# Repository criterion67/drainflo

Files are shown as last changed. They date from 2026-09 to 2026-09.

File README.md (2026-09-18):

# DrainFlo

A local, cloud free automatic vinegar doser for an HVAC condensate drain line.

Once a month it pumps one cup of distilled white vinegar into the drain line cleanout, then tells you it worked. No subscription, no cloud account, no app. Everything runs in Home Assistant on your own network.

It replaces the monthly chore of climbing into the attic with a measuring cup.

**Reference build cost: about $77 in parts plus roughly 60 g of filament.** The relay was bought on sale, and the hookup wire, connectors and leak sensor were already on hand. Per-part prices are in the [bill of materials](docs/02-bill-of-materials.md).

---

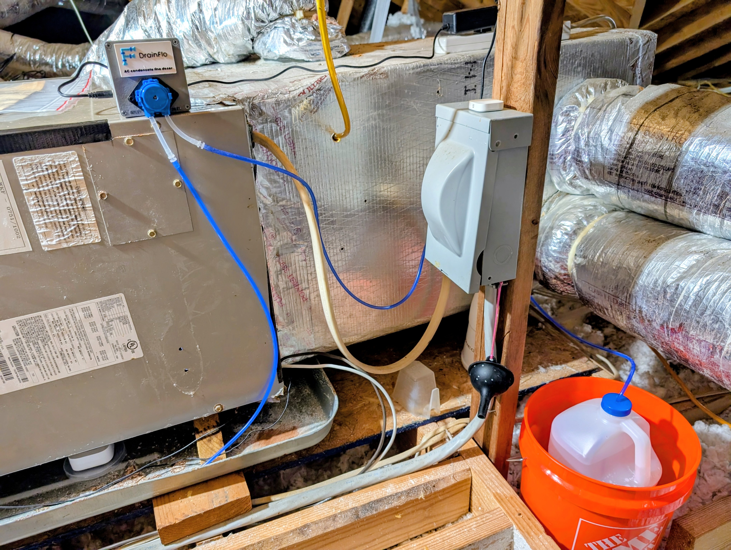
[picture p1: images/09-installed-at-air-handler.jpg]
The finished DrainFlo install at the attic air handler

*The finished install. Enclosure on the air handler, vinegar jug in its containment bucket, tubing run to the drain line cleanout.*

---
## Why I built this

Commercial automatic drain line dosers exist. The one that prompted this project is cloud dependent and uses proprietary cartridges of its own cleaning fluid, which means an account you have to keep, a service that has to stay running, and a consumable you can only buy from one place at a price they set.

None of that is necessary to squirt a cup of vinegar down a pipe once a month.

DrainFlo runs entirely on your own network. There is no account, no app, no telemetry and nothing to subscribe to. The consumable is a gallon of distilled white vinegar from the grocery store, and a gallon lasts about 16 months. If the company that made your relay disappears tomorrow, the system keeps working, because nothing in it phones home.

That principle is worth more than the money. A cloud product is only as permanent as its vendor's business model, and hardware bolted to your house should outlive that.

---

## What it does

- Doses one cup of vinegar at 05:00 on the 15th of every month
- Confirms the pump actually ran, and tells you when it did not
- Tracks how much vinegar is left in the jug and warns you before it runs out
- Force stops the pump if it ever runs longer than it should
- Runs entirely locally over Zigbee or WiFi

## What it is not

This is not a certified product. It is a pump moving liquid above your ceiling, and the thing preventing an overflow is software you are choosing to trust. **Read [docs/08-safety.md](docs/08-safety.md) before you build it.** Containment and a leak sensor are requirements, not suggestions.

---

## Documentation

| Document | Contents |
|---|---|
| [01 Overview](docs/01-overview.md) | How the system works and why it is designed this way |
| [02 Bill of materials](docs/02-bill-of-materials.md) | Every part, with sizes and substitution notes |
| [03 Enclosure](docs/03-enclosure.md) | Printing and assembling the box, lid and badge |
| [04 Plumbing](docs/04-plumbing.md) | The cleanout cap, tubing, jug and containment |
| [05 Wiring](docs/05-wiring.md) | Six connections, with the terminal map |
| [06 Home Assistant](docs/06-home-assistant.md) | Installing the package, pairing the relay |
| [07 Calibration](docs/07-calibration.md) | Measuring your pump's actual flow rate |
| [08 Safety](docs/08-safety.md) | Failure modes and what protects against each |
| [09 Troubleshooting](docs/09-troubleshooting.md) | Known issues, including the Zigbee timer problem |
| [10 ESPHome](docs/10-esphome.md) | Alternative controller with a hardware enforced runtime limit |
| [11 Shelly setup](docs/11-shelly-setup.md) | Device side setup and the three settings that protect you |

## Repository layout

```
cad/              STEP and STL files for the enclosure, lid and badge
docs/             Build documentation
esphome/          Alternative ESP32 controller: shareable project + personal config
homeassistant/    Drop in package: helpers, scripts, automations
images/           Photos, diagrams and the logo
```

---

## Printed parts

| Part | Download | Print time |
|---|---|---|
| Enclosure box | [STEP](cad/Vinegar_Doser_Box_80x80x53.step) / [STL](cad/Vinegar_Doser_Box_80x80x53.stl) | ~2 h |
| Lid with pump mount | [STEP](cad/Vinegar_Doser_Lid_pump_mount.step) / [STL](cad/Vinegar_Doser_Lid_pump_mount.stl) | ~40 min |
| DrainFlo badge, optional | [STEP](cad/DrainFlo_Badge_drop_A_full_tagline.step) | ~25 min |

About 60 g of filament all in. Print settings and orientation in [03 Enclosure](docs/03-enclosure.md).

---
## A finding worth knowing before you start

**The Shelly 1 Gen4 exposes no auto off timer when running in Zigbee mode.** The Zigbee `on_time` attribute is silently ignored: send it and the relay turns on and stays on. This is not documented by Shelly and it is the single most important thing to understand about this build, because it means the off command depends entirely on Home Assistant being alive.

DrainFlo compensates with three independent software cutoffs plus physical containment. Full detail in [docs/08-safety.md](docs/08-safety.md) and [docs/09-troubleshooting.md](docs/09-troubleshooting.md).

If you want a device side watchdog, either run the relay on WiFi instead of Zigbee, where the Shelly web interface exposes a real auto off, or use the [ESPHome controller](docs/10-esphome.md), which enforces its own maximum runtime on the microcontroller with no network involved.

---

## License

MIT. See [LICENSE](LICENSE).

## Disclaimer

DrainFlo is an independent, non commercial, open source project. It is not affiliated with, endorsed by, sponsored by, or connected to any commercial product, company or brand. Any similarity between this project's name and any trademark is unintentional and no association is implied.

Nothing is sold here and no money changes hands. The repository contains documentation and design files, published freely for anyone who wants to build their own.

## Use of AI

Portions of this project were developed utilizing AI assistance. The concept, design, physical build and all testing are mine, and all measurements in these docs came off my own bench.

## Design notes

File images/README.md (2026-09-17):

# Images

Build photos from the reference installation, in build order.

| File | What it shows |
|---|---|
| `00-parts-laid-out.jpg` | Core parts before assembly: 12V supply, Shelly 1 Gen4, barrel jacks, tubing |
| `00b-bench-setup.jpg` | Wider view of the same parts on the bench |
| `01-pump-mounted-on-lid.jpg` | Pump flange bolted to the lid with the motor hanging through the bore, box open beside it |
| `02-enclosure-wiring.jpg` | Motor leads and relay wiring joined with lever nuts, lid off |
| `03-relay-and-junctions.jpg` | Top down into the box: relay in its pocket, the two junction points, barrel jack in the wall |
| `04-enclosure-finished.jpg` | Closed enclosure with the DrainFlo badge, pump head and tubing on the outside |
| `05-cleanout-injection-point.jpg` | Tubing entering the drilled PVC cleanout cap, with the condensate safety switch on the tee |
| `06-jug-cap-tubing-and-vent.jpg` | Jug cap close up: pickup tubing pressed through, and the vent hole beside it |
| `07-jug-in-containment-bucket.jpg` | Vinegar jug standing in the containment bucket, tubing routed up to the cleanout |
| `08-leak-sensor-in-bucket.jpg` | Leak sensor in the bottom of the bucket beside the jug |
| `09-installed-at-air-handler.jpg` | The finished install at the attic air handler |

## Still to add

| Subject | Why it would help |
|---|---|
| A dose complete notification on the phone | Shows what the system actually tells you |
| Printed badge close up | The four color emboss detail |

## Diagrams

| Subject | Status |
|---|---|
| Wiring diagram, the six connection terminal map | Not yet added; see [docs/05-wiring.md](../docs/05-wiring.md) |
| DrainFlo logo | Not yet added |

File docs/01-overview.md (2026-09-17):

# 01 Overview

## The problem

An air handler pulls moisture out of the air and drains it away through a PVC condensate line. That line is dark, permanently damp and full of organic debris, which is ideal for algae and biofilm. Left alone it clogs.

When the primary line clogs, water backs up into the drain pan and out the secondary line, which usually discharges somewhere deliberately annoying so you notice. If the secondary is also blocked, or there is no float switch, the pan overflows into the ceiling.

The standard prevention is a cup of distilled white vinegar down the cleanout once a month. It works. The problem is remembering to do it, and in many houses the cleanout is in an attic.

## The approach

A small peristaltic pump, a jug of vinegar and a relay that Home Assistant can switch. Once a month the automation closes the relay for a measured number of seconds, the pump delivers one cup, and the relay opens again.

Three properties drove the design:

**Local only.** No cloud account, no vendor API, nothing that stops working when a company changes its business model. The relay speaks Zigbee or WiFi to your own network.

**No fittings in the liquid path.** The pump's own silicone tubing runs unbroken from the jug to the drain line, pressed through a hole drilled in a spare cleanout cap. Every fitting is a potential leak, so there are none.

**Containment by default.** The jug sits inside a bucket sized to hold more than the jug contains. This is not optional.

## How a dose works

```
05:00 on the 15th
        |
        v
Is the relay reachable?  ---- no ---->  raise fault, notify, stop
        |
       yes
        v
Close the relay
        |
        v
Wait 5 seconds, did it actually report on?  ---- no ---->  force off, raise fault, notify
        |
       yes
        v
Wait the remaining dose time
        |
        v
Open the relay
        |
        v
Decrement dose counter, update next due date, notify success
```

The verification step matters. A relay that has silently dropped off the network will accept a turn on command that goes nowhere, and without checking you would believe the drain line was dosed when it was not.

## Components of the system

**Pump.** A 12V DC peristaltic dosing pump. Peristaltic because the rollers occlude the tube when idle, which means the pump itself blocks backflow and no check valve is needed. Also self priming and tolerant of running dry.

**Relay.** A dry contact relay that can be powered from the same 12V supply. Dry contact rather than a mains switch means one power supply for the whole build.

**Controller.** Home Assistant. It holds the schedule, runs the dose, verifies it, counts remaining vinegar and raises the alarms.

**Enclosure.** A printed box that holds the relay and carries the pump on its lid, so the pump motor hangs inside and the wet end stays outside.

**Containment.** A bucket under the jug, with a leak sensor in the bottom of it.

## Design decisions worth explaining

**Dose by time, not by volume.** There is no flow meter. The pump runs at a known rate, so the dose is a calibrated number of seconds. This drifts as the pump tube takes a set, which is why [07 Calibration](07-calibration.md) tells you to re measure occasionally.

**05:00 on a fixed day.** Early morning puts the attic near its daily minimum temperature, which matters because these pumps are typically rated only to 40C and an attic exceeds that by afternoon. A fixed day of the month rather than a rolling 30 day countdown keeps the schedule predictable and lets you avoid whatever day your other notifications land on.

**The counter is open loop.** Home Assistant cannot see inside the jug. The dose counter is a budget that decrements on each dose and resets when you tell it you refilled. If you refill and never acknowledge it, the count drifts low. The consequence is a false low vinegar warning, not a failure, but it is worth knowing.

**The fault flag does not self clear.** If a dose is missed, the warning stays up until you dismiss it. A relay coming back online does not mean the drain line got its vinegar.

## Next

Start with [02 Bill of materials](02-bill-of-materials.md).

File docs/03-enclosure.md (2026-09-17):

# 03 Enclosure

Three printed parts. The box holds the relay, the lid carries the pump, and the badge is decorative.

## Files

| Part | Download | What it is |
|---|---|---|
| Box | [STEP](../cad/Vinegar_Doser_Box_80x80x53.step) / [STL](../cad/Vinegar_Doser_Box_80x80x53.stl) | 80 x 80 x 53 mm box with relay pocket and barrel jack hole |
| Lid | [STEP](../cad/Vinegar_Doser_Lid_pump_mount.step) / [STL](../cad/Vinegar_Doser_Lid_pump_mount.stl) | Lid with 31 mm pump bore, reinforcing boss and M3 slots |
| Badge | [STEP](../cad/DrainFlo_Badge_drop_A_full_tagline.step) | Optional four color badge, 60 x 34 x 2.1 mm. STEP only, see the Badge section |

STEP files are provided so you can modify dimensions. STL files are provided for printing directly.

## Print settings

Developed on a Bambu Lab P2S with a 0.4 mm nozzle.

| Setting | Value | Why |
|---|---|---|
| Layer height | 0.20 mm | |
| Wall loops | 4 | The lid boss carries a cantilevered motor |
| Infill | 30% | |
| Supports | None | Both parts are self supporting in the orientations below |
| Material | PLA or PETG | PETG if your attic runs above roughly 55C |

**Orientation matters.** The box prints opening upward, floor on the plate. The lid prints flat face down with the reinforcing boss pointing up. Printing the lid the other way up needs supports under the entire boss overhang.

## Box features

- **Relay pocket**, 42.05 mm between the internal rails. A Shelly 1 Gen4 is 42.0 mm wide, so this is a press fit with essentially no clearance. If yours will not seat, file the inner faces of the two rails. They only locate the relay and carry no load.
- **11 mm hole** in one wall for the panel mount barrel jack, with an 18 mm reinforcing boss on the inside so the jack's nut has a flat seat and something to torque against.
- **Four corner posts** with 2.8 mm pilot holes, 7 mm deep from the rim.

## Lid features

- **31 mm bore** offset from center, positioned so the motor hangs beside the relay rather than above it. The relay's height therefore does not constrain the design.
- **6 mm reinforcing boss** on the inner face, bringing material under the pump flange to 8 mm total.
- **Two M3 slots** elongated along the bore's long axis, covering flange screw pitches from about 46 to 49 mm.

## Assembly

1. **Test fit the relay** in the box pocket before anything else. File the rails if tight.
2. **Fit the barrel jack** through the 11 mm hole. Gasket outside, nut inside against the boss. Hand tight plus a little.
3. **Mount the pump to the lid.** Flange on the outside of the lid, motor hanging through the bore. M3 x 16 screws down through the flange, washers and nuts on the inside of the boss. **Do this with the lid off the box**, flat on a bench. Reaching inside a 53 mm box with two wrenches is miserable.
4. **Wire it** per [05 Wiring](05-wiring.md), still with the lid off.
5. **Close the lid** with four M3 x 10 screws into the corner posts. Do not exceed 10 mm: past that the screw leaves the pilot hole and enters the hollow post, where it grips nothing and can split it.

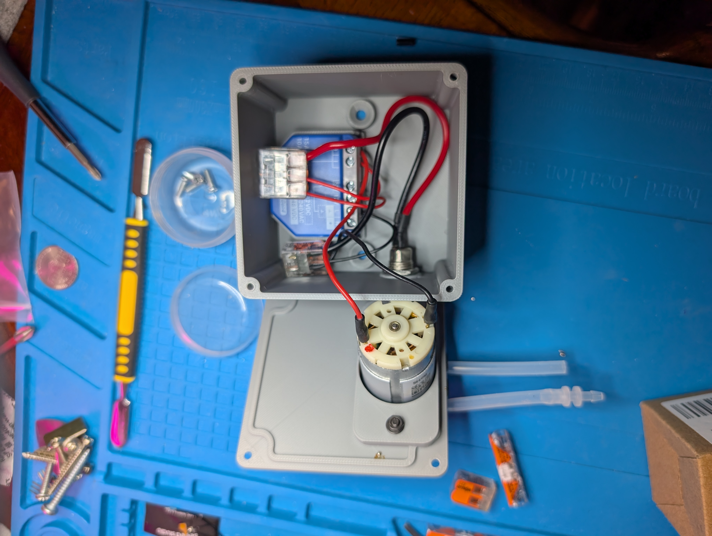
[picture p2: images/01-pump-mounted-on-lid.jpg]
Pump bolted to the lid with the motor hanging through the bore

*Pump mounted to the lid before the lid goes on the box. Flange outside, motor hanging through the bore. Do this on a bench, not reaching into a 53 mm box.*

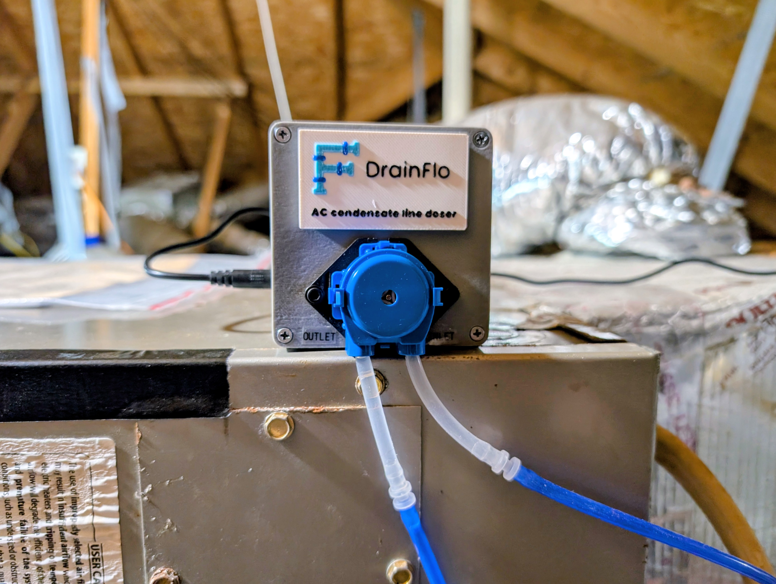
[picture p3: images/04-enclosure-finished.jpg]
The closed enclosure with the DrainFlo badge

*The finished enclosure. Badge above the pump bore, INLET and OUTLET labelled on the lid.*
## Badge

Optional. Four colors in a single 0.6 mm raised layer band, so a multi material system purges once rather than per feature.

The STEP file imports as one object with four named bodies. Assign a filament to each: base black, pipe light blue, joints dark blue, text white.

Print four at once. Purge waste is charged per color change per layer, not per object, so spares are nearly free.

Attach with VHB or double sided foam tape to the lid's outer face, above the pump bore. Clearances are tight, roughly 2 mm to the bore and 2.6 mm to the nearest corner screw recess, so do not scale it up.

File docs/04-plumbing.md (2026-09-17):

# 04 Plumbing

There are no fittings in the liquid path. The pump's own silicone tubing runs unbroken from the jug to the drain line. Every joint you do not have is a joint that cannot leak.

## The cleanout cap

Most condensate drain lines have a vertical riser with a cap on top, which is where you would normally pour vinegar. Many are friction fit rather than glued.

**Buy a spare cap and drill that one.** They cost a couple of dollars and it keeps your original as a fallback.

1. Identify your cap size. 3/4 inch Schedule 40 is common; the part number is usually moulded into it.
2. Drill a **3/16 inch hole** in the top of the spare cap. That is 4.76 mm against 5 mm tubing, which gives a press fit that grips.
3. Push the tubing through. Warm or wet the end and twist it. If you drill 5 mm it will slide out over time.
4. Cut the tubing so it hangs about **3 inches into the riser**, ending in open air.
5. Fit a zip tie on the tubing just above the cap as a mechanical stop, so it cannot creep down over the years.

**The tube end must never sit in standing water.** If it does, you give condensate a path to wick back up.

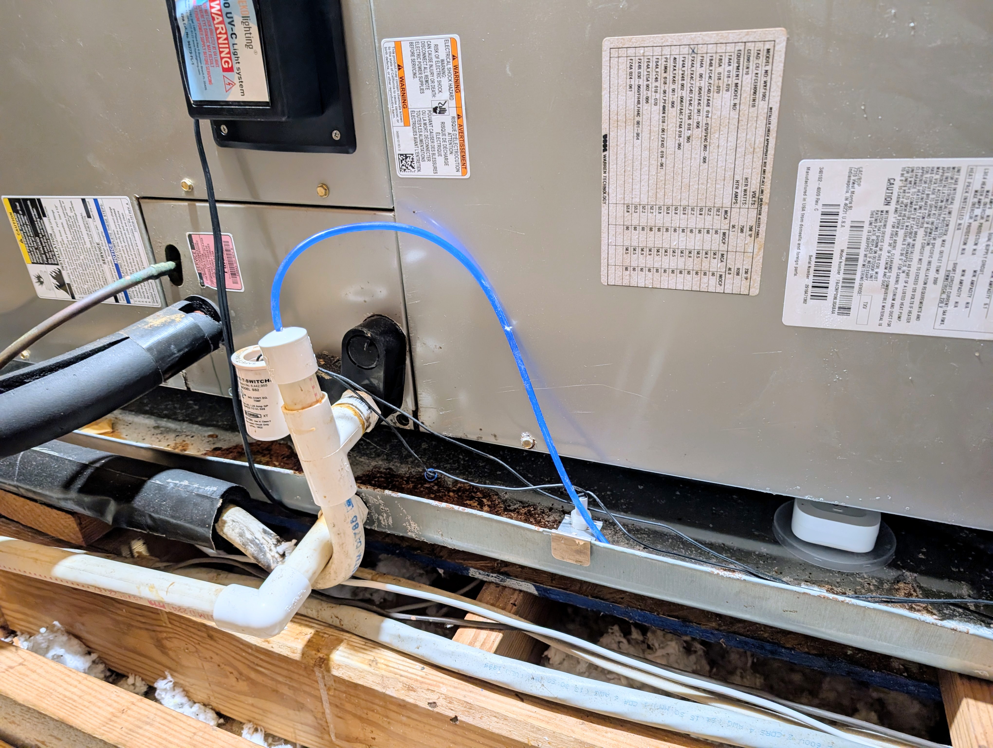
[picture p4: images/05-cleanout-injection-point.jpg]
Tubing entering the drilled PVC cleanout cap

*The injection point. Tubing pressed through a 3/16 inch hole drilled in a spare cleanout cap, hanging about 3 inches into the riser. No fittings anywhere in the liquid path.*
## Why not a fitting

Earlier iterations of this build used a threaded stack: a glued female adapter, a reducing bushing and a barbed fitting. It works but adds three leak paths, several inches of height, and a corrosion question. Vinegar attacks brass, and stainless grade matters above 50C.

A hole and a press fit has none of those problems and costs nothing.

## The jug

Use the jug the vinegar came in. HDPE, rigid, already the right shape. Drill two holes in its cap.

**Pickup hole:** 3/16 inch, press fit for the tubing. Cut the tube so it ends about 5 mm off the bottom of the jug. Close enough to draw nearly all of it, far enough that it cannot seal against the floor.

**Vent hole:** about 3 mm. This one must stay in the **air space above the liquid**, never below it.

The vent exists because as the pump draws liquid out, air has to get back in or the jug collapses and the pump starves. Attic heat expanding the air above the vinegar is the second reason.

**A vent tube must not reach into the liquid.** If it does, you have built a siphon and the jug will empty itself.

If you fit a short stub of tube in the vent hole, run it outside the jug, loop it downward, and end it inside the containment bucket. Attic heat can push vapour or a little liquid out, and the loop catches it.

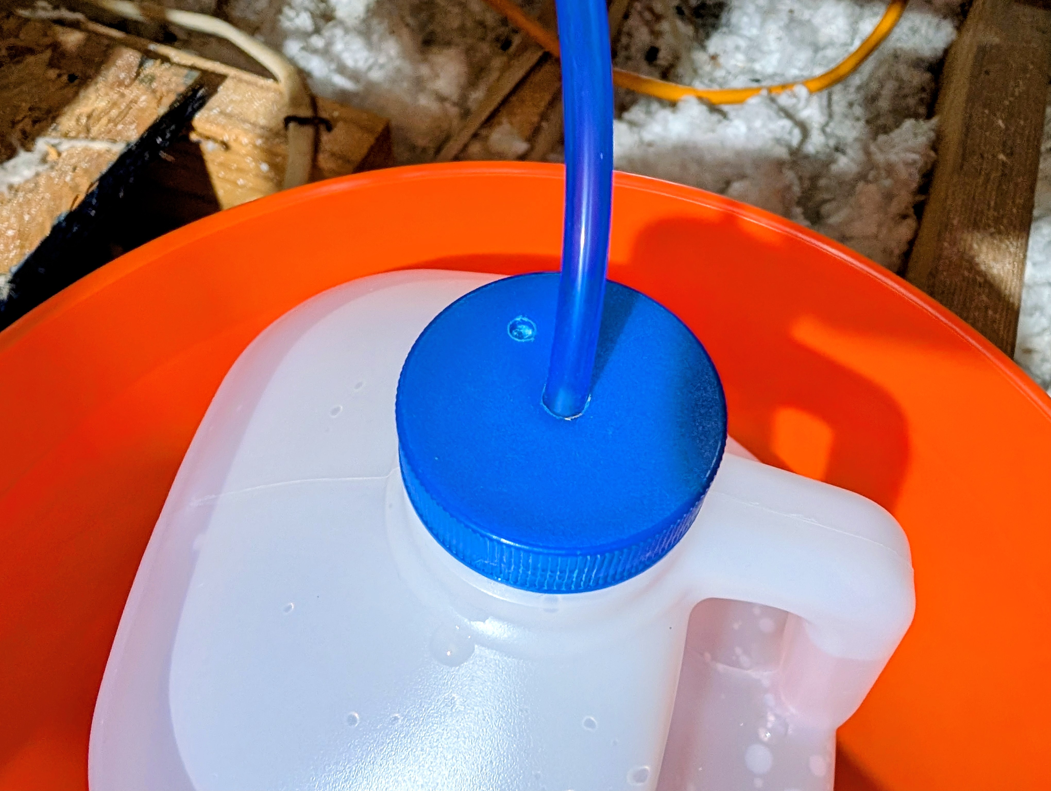
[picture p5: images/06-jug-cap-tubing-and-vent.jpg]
Jug cap with the pickup tubing pressed through and the vent hole beside it

*The jug cap. Pickup tubing press fit through a 3/16 inch hole, and the 1/8 inch vent hole beside it, staying in the air space above the liquid.*
## Containment

**This is a requirement, not a suggestion.**

The jug sits inside a bucket whose capacity exceeds the jug's. A 1 gallon jug in a 2 gallon bucket gives you a full jug failure fully contained.

Put a **water leak sensor in the bottom of the bucket**, beside the jug. Containment without detection means you find out at the next refill.

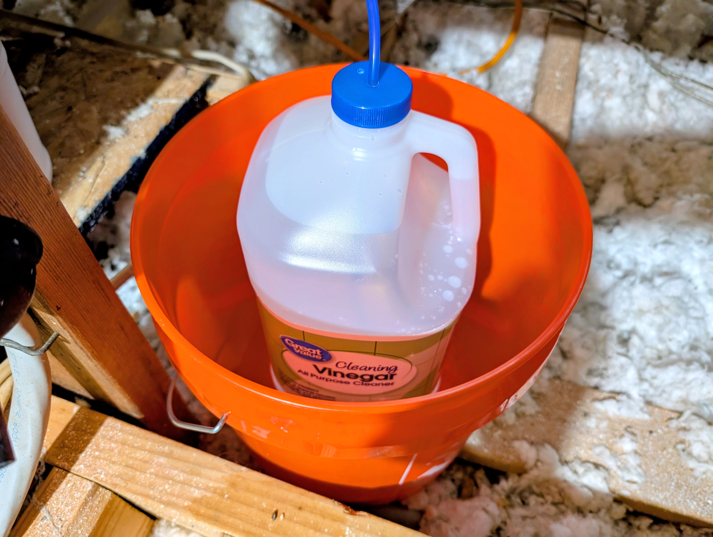
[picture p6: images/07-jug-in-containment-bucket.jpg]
Vinegar jug standing in the orange containment bucket

*A 1 gallon jug inside a 2 gallon bucket. A full jug failure is fully contained.*

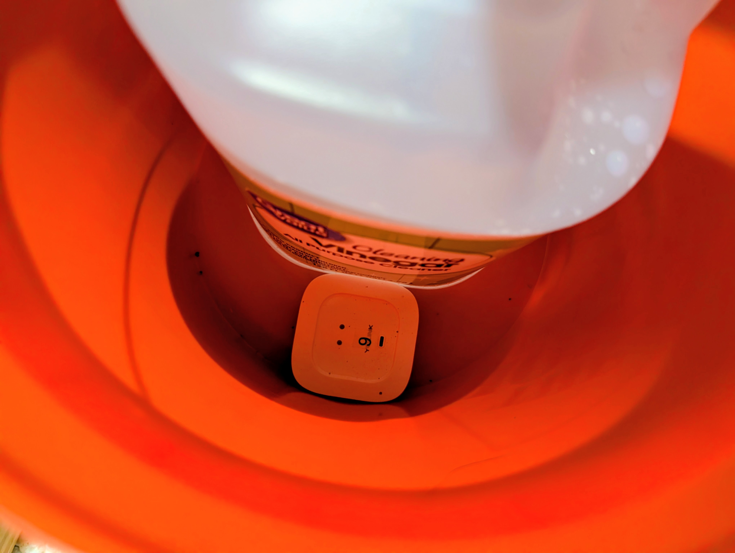
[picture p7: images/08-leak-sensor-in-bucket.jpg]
Leak sensor in the bottom of the bucket beside the jug

*The leak sensor goes in the bottom of the bucket, beside the jug. Containment without detection just delays the discovery.*
## Layout

Two rules:

**The jug sits lower than the injection point.** The pump self primes easily over that height, and it means no head pressure is trying to push liquid toward the drain line if anything fails.

**Nothing pulls on the jug.** Route the tubing so no tug can tip it inside the bucket.

## Which tube is which

Run the pump and feel both ends. One will be under suction, and that is the inlet: it goes into the jug. The other goes to the cap.

A peristaltic pump is a brushed DC motor, so reversing the leads reverses the flow direction. If your inlet and outlet are the wrong way round, swap the two pump wires.

Mark both tubes as soon as you know.

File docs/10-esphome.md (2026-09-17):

# 10 ESPHome controller

An alternative to the commercial relay. Costs less, requires soldering, and gives you something the Zigbee relay cannot: **a maximum runtime enforced on the microcontroller itself**, with no network involved.

If Home Assistant dies mid dose, the ESP32 still shuts the pump off.

## Which to choose

| | Commercial relay | ESPHome |
|---|---|---|
| Controller cost | ~$28 | ~$8 |
| Soldering | None | Yes |
| Hardware watchdog on Zigbee | **No** | **Yes** |
| Hardware watchdog on WiFi | Yes | Yes |
| Setup | Pair and go | Flash and go |

## Parts

| Part | Spec | Approx. |
|---|---|---|
| Seeed XIAO ESP32C3 | With the external antenna it ships with | $5 |
| IRLB8721PBF | Logic level N channel MOSFET, TO-220 | $1 |
| Resistors | One 100 ohm, one 10k | pennies |
| MP1584EN module | Adjustable buck converter | $2 |

**Use the C3, not the S3.** The C3 has no PCB antenna at all and relies entirely on the external one it ships with, which is what you want through attic framing. The S3 buys nothing here and runs warmer.

**Use the IRLB8721, not the IRLZ44N** that most tutorials name. The IRLZ44N specifies its on resistance at 5 V gate drive and is marginal on a 3.3 V GPIO pin. The IRLB8721 has guaranteed on resistance at lower gate voltages and much lower gate charge.

**No flyback diode needed.** At roughly 12 switching cycles a year against a 0.4 A motor, it earns nothing.

## Circuit

One 12 V supply enters through the panel barrel jack and feeds two things: the pump, and an MP1584EN buck converter that makes 5 V for the XIAO.

```
12V+ ──┬── Pump +
       └── MP1584EN IN+ ── (set to 5.0V) ── XIAO 5V pin

Pump − ── MOSFET drain
MOSFET source ── 12V−
MOSFET gate ── 100 ohm ── XIAO GPIO5
MOSFET gate ── 10k ── 12V−

12V− ── XIAO GND, MP1584EN IN−, MOSFET source   (all common)
```

**Set the buck to 5.0 V with a meter before connecting the XIAO.** These modules ship at an arbitrary voltage set by a multi turn trimpot. Feeding the 5 V pin anything above about 5.5 V destroys the board.

**The 10k pulldown is not optional.** Without it the gate floats during boot and the pump can twitch.

**All grounds must be common.** The gate voltage is measured against source, so an ungrounded reference means unpredictable switching.

### Two supplies instead

You can skip the buck and power the XIAO from a separate USB-C supply. It works, and removes the trimpot step. **You must still tie the two grounds together**, or the gate has no reference to the pump's return path.

The reason the buck is preferred: the enclosure has one hole for one power connector, and nowhere for a second cord.

## Pin choice

GPIO5, which is silkscreened D3. Confirm against the pinout for your board.

**Avoid GPIO2, GPIO8 and GPIO9.** They are strapping pins on the ESP32C3 and pulling them at boot changes how the chip starts.

## Two configurations

**[`esphome/drainflo.yaml`](../esphome/drainflo.yaml)** is the shareable project file. It contains no credentials, sets up Improv provisioning over both USB serial and Bluetooth, and carries the `dashboard_import` block that lets anyone adopt the device into their own ESPHome Device Builder. Flash this one.

**[`esphome/drainflo-personal.yaml`](../esphome/drainflo-personal.yaml)** is a conventional config using `!secret` for WiFi, API and OTA credentials. Use this if you would rather manage the device the normal way.

## Flashing

Flash the first time over USB at a bench, not in the attic. After that everything is OTA.

Provisioning is via Improv: either plug it into a computer and use the ESPHome web installer, or use Bluetooth from the Home Assistant app. No credentials are baked into the firmware.

## What it exposes

| Entity | Purpose |
|---|---|
| Dispense Dose | Runs one full dose |
| Prime Pump | 20 seconds, for filling the line |
| Stop Pump | Aborts everything and forces off |
| Dose Duration | Your calibrated seconds per cup |
| Pump Running | Binary sensor |
| Restart ESP | |

**The raw pump switch is deliberately not exposed.** It is marked internal, so everything goes through the dose script and the pump cannot be left running by a stray toggle in the Home Assistant UI.

## Two layers of runtime protection

**The script** turns the pump off after `dose_seconds`.

**The switch itself** kills it at `max_run_seconds`, 300 by default, through an `on_turn_on` automation with `mode: restart`. This runs on the ESP with no network involved, so a dead WiFi link or a crashed Home Assistant still ends with the pump off.

That second layer is the entire reason to choose this over the Zigbee relay. See [08 Safety](08-safety.md).

## Using it with the Home Assistant package

The package in `homeassistant/packages/drainflo.yaml` switches `switch.drainflo`. The ESPHome device does not expose a switch, it exposes a button.

Change the dose branch to press `button.drainflo_dispense_dose` instead of toggling a switch, and drop the delay and the turn off, since the device handles its own timing. The safety cutoff and startup force off branches become redundant but are harmless to leave in place.

**Containment is still required.** A hardware watchdog reduces the risk, it does not remove it.

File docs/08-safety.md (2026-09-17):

# 08 Safety

Read this before building. It is the most important document in the repository.

## What you are building

A pump that moves liquid, mounted above a ceiling, with software deciding when it stops.

That is the whole risk in one sentence. Everything below follows from it.

## The primary failure mode

**The relay closes and does not open.**

If that happens and nothing intervenes, the pump keeps running until the jug is empty. A gallon of vinegar goes into your drain line far faster than it can drain, backs up, and overflows the pan into the ceiling.

## What the Shelly does not do

**In Zigbee mode the Shelly 1 Gen4 provides no device side auto off.**

The Zigbee `on_time` attribute is silently ignored. Publishing `{"state": "ON", "on_time": 300}` turns the relay on and it stays on indefinitely, with no error and no indication that the timer was dropped. A plain `{"state": "ON"}` to the same topic works, which confirms the topic is correct and the attribute specifically is being discarded.

This is not documented by Shelly. It was found by testing, and it is the reason this document exists.

**The consequence: the off command depends entirely on Home Assistant.** If Home Assistant is down, restarting, or has lost the network when a dose is in progress, nothing in the relay will stop the pump.

## What protects you

Four layers, in order from first to last.

**1. The dose sequence turns the pump off.** Normal operation. Turn on, wait, turn off.

**2. A safety cutoff automation.** Triggers when the switch has been on for 6 minutes against a 110 second dose, forces it off, and pushes an urgent notification. This catches a dose sequence that died part way through.

**3. A startup force off.** On every Home Assistant start, the switch is commanded off. This catches the case where Home Assistant crashed mid dose and came back with the relay still closed.

**4. Physical containment.** The jug sits in a bucket larger than the jug. Even if every software layer fails, the vinegar that is not already in the drain line ends up in the bucket.

**The gap that remains:** Home Assistant down for an extended period with the relay closed. Layers 1 to 3 are all software. Layer 4 is what stands between that scenario and your ceiling.

## Requirements, not suggestions

- **A containment vessel that holds more than the jug does.** A 1 gallon jug goes in a 2 gallon bucket.
- **A leak sensor in the bottom of that vessel.** Containment without detection just delays the discovery.
- **Do not skip the safety cutoff automation.** It is in the package for a reason.

## If you want a real hardware watchdog

Two options:

**Run the relay on WiFi instead of Zigbee.** The Shelly's web interface exposes a genuine auto off setting that the device enforces itself. Set it to 300 seconds. Verify it actually works by watching a test dose before you trust it.

**Use the ESPHome controller instead.** [esphome/drainflo.yaml](../esphome/drainflo.yaml) enforces a hard maximum runtime on the microcontroller itself. A dead network or a crashed Home Assistant does not affect it.

## Chemical notes

**Use vinegar, not bleach.** Either ordinary distilled white vinegar at 5 percent acetic acid or cleaning vinegar at 6 percent works. The reference build runs on cleaning vinegar. The stronger acid is no problem for the liquid path, since silicone tubing is rated excellent for 10 percent acetic acid in water, and a higher concentration is if anything more effective against biofilm. What has not been verified here is whether 6 percent behaves differently from 5 against a drain pan or evaporator coil in a backup situation, so if that matters to you, use the 5 percent.

**Never use bleach in a condensate drain line.** It corrodes the evaporator coil and the drain pan.

**If you reuse a bleach jug, rinse it thoroughly and let it dry open first.** Residual hypochlorite meeting acetic acid releases chlorine gas, and an attic is a poor place for that.

**Silicone tubing is fine with dilute acetic acid.** It is rated excellent for 10 percent acetic acid in water. Metal fittings are where the compatibility questions start, which is another reason this build has none.

## Temperature

Most small peristaltic pumps are rated for 0 to 40C ambient. An attic exceeds that on a summer afternoon in most of the United States.

Dosing in the early morning puts the run near the attic's daily minimum, which is why the schedule is at 05:00. Idle storage at high temperature is much less stressful than running at it, but it is a real constraint and worth knowing if you are considering a different schedule.

## Electrical

Everything in this build is 12V DC. There is no mains wiring anywhere.

If you substitute a mains switched relay, that is a different project with different requirements, and this document does not cover it.

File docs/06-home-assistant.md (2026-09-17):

# 06 Home Assistant

## Pairing the relay

### Zigbee (Zigbee2MQTT)

The Shelly 1 Gen4 ships in Matter profile and must be switched to Zigbee first.

**Update the firmware before switching.** Zigbee OTA is not supported, so once it is on Zigbee you cannot update it without switching back.

Two ways to switch:

- **Web interface.** Settings has a Matter to Zigbee toggle, then a Zigbee menu with Start pairing. Status reads Steering while discoverable and Joined on success.
- **Button.** Five quick presses switches profile and opens a 3 minute inclusion window. Three presses reopens it. The presses have to be genuinely fast.

**Switching wipes every setting except the WiFi configuration.** Configure anything device side after the switch, not before.

Name the device `DrainFlo` in Zigbee2MQTT, which yields `switch.drainflo`. Resist adding a room or descriptor, since Z2M builds the entity_id from the friendly name.

### WiFi

Power the relay, join the access point it broadcasts, and browse to `http://192.168.33.1`. Point it at your network, then give it a DHCP reservation.

**On WiFi you get a real auto off timer** in the Shelly web interface. Set it to 300 seconds. This is a genuine device side watchdog and it is the main reason to prefer WiFi for this build. Full device side procedure in [11 Shelly setup](11-shelly-setup.md); see also [08 Safety](08-safety.md).

## Installing the package

Enable packages in `configuration.yaml` if you have not already:

```yaml
homeassistant:
  packages: !include_dir_named packages
```

Copy [`homeassistant/packages/drainflo.yaml`](../homeassistant/packages/drainflo.yaml) into `config/packages/` and restart Home Assistant.

### Three things to change first

| Placeholder | Occurrences | Change to |
|---|---|---|
| `notify.mobile_app_pixel_9` | 9 | Your own notify target |
| `switch.drainflo` | 11 | Your relay's entity_id |
| `delay: seconds: 105` | 1 | Your calibrated dose time minus 5 |

The `Quiet Notices` channel is Android specific. On first use Android creates it silent at low importance. **iOS users should remove the `channel` and `importance` keys** from the notification data blocks.

### Seed the helper values

After the restart:

- `input_number.drainflo_doses_remaining` to **16** for a full gallon
- `input_datetime.drainflo_next_dose` to **the 15th of next month**

## What gets created

**Helpers**

| Entity | Purpose |
|---|---|
| `input_number.drainflo_doses_remaining` | Open loop dose budget, 16 per gallon |
| `input_boolean.drainflo_pump_fault` | Drives the fault card, does not self clear |
| `input_boolean.drainflo_refill_active` | Drives the refill card |
| `input_datetime.drainflo_refill_snooze_until` | 7 day snooze deadline |
| `input_datetime.drainflo_next_dose` | Display only readout |

**Scripts**

| Entity | Purpose |
|---|---|
| `script.drainflo_dose_complete` | Updates the next dose readout, logs |
| `script.drainflo_refilled` | Resets the budget to 16 |
| `script.drainflo_refill_snooze` | Pushes the snooze out 7 days |
| `script.drainflo_clear_fault` | Dismisses the fault state |

**Automations**

| Entity | Purpose |
|---|---|
| `automation.drainflo_dosing` | Dose, verify, safety cutoff, startup force off, offline warning |
| `automation.drainflo_refill_reminder` | Daily low vinegar level check |

## Testing before you trust it

**Run `automation.drainflo_dosing` manually.** Triggering by hand skips the day of month condition, so it doses regardless of the date. Do this with the outlet tube in a container, not in the drain line.

Watch for: the relay closing, the pump running for your dose time, the relay opening on its own, a success notification, and the counter dropping by one.

Afterwards, reset the counter and the next dose date if you want a clean slate.

**Test the safety cutoff too.** Turn `switch.drainflo` on manually and leave it. After 6 minutes it should force off and push on the urgent channel. This is the layer that matters most, so confirm it works rather than assuming.

## Dashboard cards

Two conditional cards, one per boolean, in whatever notification area your dashboard uses:

```yaml
type: conditional
conditions:
  - condition: state
    entity: input_boolean.drainflo_pump_fault
    state: "on"
card:
  type: markdown
  content: >-
    ### DrainFlo pump fault

    The monthly dose did not complete. Dose manually if the line needs it,
    then dismiss.
  card_mod: {}
```

```yaml
type: conditional
conditions:
  - condition: state
    entity: input_boolean.drainflo_refill_active
    state: "on"
card:
  type: markdown
  content: >-
    ### DrainFlo vinegar low

    {{ states('input_number.drainflo_doses_remaining') | int }} doses left.
```

Add tap actions calling `script.drainflo_clear_fault` and `script.drainflo_refilled` respectively. Put a confirmation on both if the dashboard lives on a wall tablet where a stray tap is plausible.

## A note on the reference instance

The reference build reuses a helper named `input_datetime.hvac_drain_line_due_date` and a script named `script.hvac_drain_line_cleaned`, inherited from the manual reminder system DrainFlo replaced. The package uses clean `drainflo_` names throughout. Functionally identical.

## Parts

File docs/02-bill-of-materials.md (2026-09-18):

# 02 Bill of materials

Prices are approximate as of late 2026 and exclude shipping.

**No affiliate links anywhere in this repository.** Every link is a plain product link with tracking parameters stripped. If you fork this and add referral links, please say so in your README.

Links are provided for convenience and go stale quickly. **The spec column is what actually matters.** Match the specification, not the listing.

## Core parts

| Part | Spec | Approx. | Link | Notes |
|---|---|---|---|---|
| Peristaltic dosing pump | Kamoer NKP, 12V DC, 3mm ID x 5mm OD | $10 | [link](https://www.amazon.com/dp/B07GWJ78FN) | See selection notes below |
| Dry contact relay | Shelly 1 Gen4, UL listed | $28 | [link](https://www.amazon.com/dp/B0H8YW595V) | Often on sale; the reference build paid $18. Must accept 12V DC power. See alternatives below |
| Silicone tubing | 3mm ID x 5mm OD, 9.8 ft | $9 | [link](https://www.amazon.com/dp/B0FMF45JZH) | Must match the pump's tube size |
| Panel mount barrel jack | 5.5 x 2.1 mm, 11 mm panel hole | $6 for 6 | [link](https://www.amazon.com/dp/B0GGN5MWH5) | Only one needed |
| 12V DC power supply | 12V 2A, center positive, 5.5 x 2.1 mm plug | $7 | [link](https://www.amazon.com/dp/B0BZP8CYD1) | The plug must be 2.1 mm to match the jack; a 2.5 mm plug sits loose. 1A is enough. Meter the polarity before use |
| Vinegar | 1 gallon, cleaning or distilled white | $4 | [link](https://www.walmart.com/ip/GV-Vinegar-128oz/15941853266) | Its own HDPE jug is the reservoir |
| Containment bucket | 2 gallon | $5 | [link](https://www.homedepot.com/p/The-Home-Depot-2-gal-Homer-Bucket-RG502HD/316355946) | Must exceed the jug's capacity |
| Water leak sensor | Any Home Assistant compatible | $15 to $30 | see below | Goes in the bottom of the bucket. Options in the next section |
| Wire connectors | Two 3 way joints, one 2 way | under $1 | hardware store | Plain wire nuts are fine. Lever nuts are nicer to work with: [WAGO 221-413](https://www.amazon.com/dp/B0GLHLRZR4) $7 for 10 and [221-412](https://www.amazon.com/dp/B072PT3JNL) $6 for 10 |
| Hookup wire | 18 AWG, a few feet | on hand | [link](https://www.amazon.com/dp/B0DXKKCS5R) | Any 18 AWG will do. The reference build used 18/3 thermostat cable left over from another job |
| Spare PVC cleanout cap | Matching your existing cap | $2, optional | hardware store | Recommended. The reference build drilled the cap already on the riser, which works but leaves no undrilled cap to seal the line with later |
| M3 x 16 machine screws, nuts, washers | 2 of each | $2 for both sizes | hardware store | Pump flange to lid |
| M3 x 10 machine screws | 4 | included above | hardware store | Lid to box |

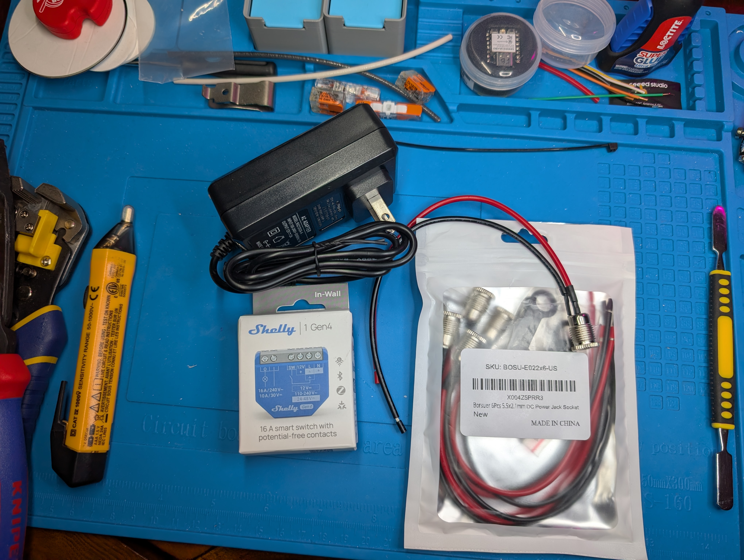
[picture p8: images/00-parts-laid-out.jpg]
Core parts laid out on the bench before assembly

*Most of the core parts: 12V supply, Shelly 1 Gen4, panel mount barrel jacks, silicone tubing, lever nuts.*
## Leak sensor options

**This is the part people skip, and it is the one that tells you the containment bucket did its job.** Without it you find out at the next refill.

Any sensor Home Assistant can see will do. A few that work:

| Sensor | Protocol | Approx. | Link |
|---|---|---|---|
| YoLink YS7903 | YoLink, needs a YoLink hub | $25 | [link](https://www.amazon.com/dp/B07Z7QWJBP) |
| ThirdReality WL2 | Zigbee, needs a Zigbee coordinator | $15 | [link](https://www.amazon.com/dp/B0GK19F6Z2) |
| Aqara T1 | Zigbee, needs a Zigbee coordinator | $18 | [link](https://www.amazon.com/dp/B0DWXHMFQS) |
| Shelly Flood S Gen4 | WiFi, Bluetooth, Zigbee or Matter | $30 | [link](https://www.amazon.com/dp/B0H3QG45XL) |

The reference build uses the YoLink because one was already on hand.

**If you have no hub of any kind, the Shelly Flood S Gen4 is the one to get.** Per its listing it speaks WiFi as well as Zigbee and Matter, so it can reach Home Assistant on your network alone. The other three need a coordinator or bridge you may not own, which turns a $15 sensor into a $60 purchase.

**Put it in the bottom of the bucket, beside the jug.** Not on the platform next to the air handler. A pan sensor tells you the drain line clogged, which is a different failure. This one tells you the vinegar jug leaked.
## Pump selection

The build was developed around a **Kamoer NKP 12V** with a 3mm ID x 5mm OD tube. Any similar 12V DC peristaltic dosing pump will work. What to match:

- **12V DC brushed motor.** Avoid stepper driven pumps, which need a driver board.
- **Tube size 3mm ID x 5mm OD.** If yours differs, the cap hole and tubing in the docs change accordingly.
- **Flow rate roughly 70 to 150 mL/min.** Faster pumps dose too coarsely for a one cup target. The measured unit in this build delivered about 135 mL/min.
- **Snap in pump head if available.** Tube replacement without tools is worth a lot when the pump lives in an attic.

The enclosure CAD assumes a **29 mm diameter, 48.5 mm long motor with a 54.5 x 40.3 mm flange and screws 47 to 48.5 mm apart.** The lid's mounting holes are slots, so the pitch tolerance is covered, but a very different motor needs the bore resized.

## Relay selection

The relay must satisfy three things:

1. **Dry contact output** so the pump is switched independently of the relay's own power
2. **12V DC input**, so one supply runs everything
3. **Local control** from Home Assistant

The Shelly 1 Gen4 meets all three. Note the important caveat about its Zigbee mode in [09 Troubleshooting](09-troubleshooting.md).

**Do not use the Shelly 1 Mini Gen4.** It has dry contacts but is AC powered only, with no DC input.

Other dry contact relay modules that take 12V DC work equally well. Generic Zigbee dry contact modules are around $17.

## Alternative: ESP32 controller

Instead of a commercial relay you can drive the pump from a microcontroller. This costs less and gives you a hardware enforced maximum runtime, at the price of soldering.

| Part | Approx. |
|---|---|
| Seeed XIAO ESP32C3 | $5 |
| IRLB8721PBF MOSFET | $1 |
| 100 ohm and 10k resistors | pennies |
| MP1584EN buck converter module | $2 |

Not yet built, so no links. These are stock parts available from any electronics supplier.

Full detail in [10 ESPHome](10-esphome.md).

**Use the IRLB8721, not the IRLZ44N** that most tutorials name. The IRLZ44N specifies its on resistance at 5V gate drive and is marginal on a 3.3V microcontroller pin.

## Printed parts

About 60 g of filament total. PLA is adequate for an attic in a temperate climate; consider PETG if yours runs very hot.

| File | Print time | Notes |
|---|---|---|
| [Box](../cad/Vinegar_Doser_Box_80x80x53.stl) | ~2 h | Opening up, no supports |
| [Lid](../cad/Vinegar_Doser_Lid_pump_mount.stl) | ~40 min | Flat face down, boss up, no supports |
| [Badge](../cad/DrainFlo_Badge_drop_A_full_tagline.step) | ~25 min | Optional, four colors, STEP only |

Settings in [03 Enclosure](03-enclosure.md).

## Tools

- 3D printer, 0.4 mm nozzle
- Drill with a 3/16 inch bit for the cap and jug, and 11 mm or 7/16 inch for the barrel jack
- Calipers
- Multimeter, to confirm barrel jack polarity
- Measuring cup, for calibration
- Two small wrenches for the M3 hardware
- WAGO lever nuts or a small terminal block

## Not required

- No check valve. The peristaltic pump provides that.
- No flyback diode. At roughly 12 switching cycles a year, a 0.4 A motor will not measurably wear a 10 A relay.
- No fittings, barbs or adapters. The tubing runs unbroken.

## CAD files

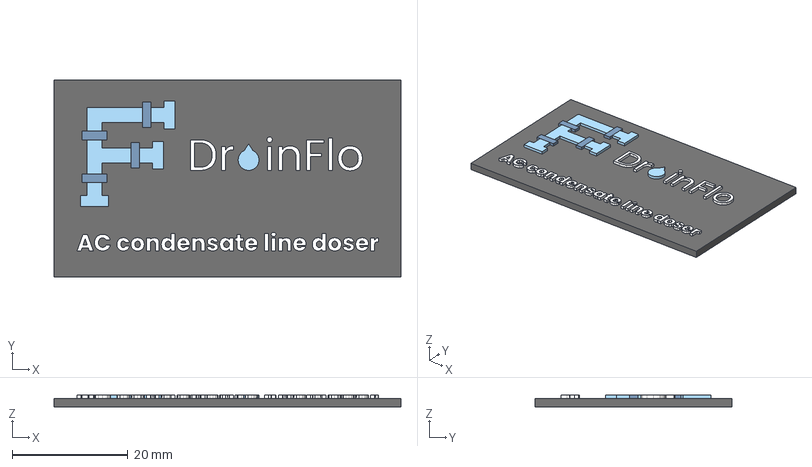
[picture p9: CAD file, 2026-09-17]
cad/DrainFlo_Badge_drop_A_full_tagline.step
60.0 x 34.0 x 2.10 mm
base
pipe_lightblue
joints_darkblue
text_white

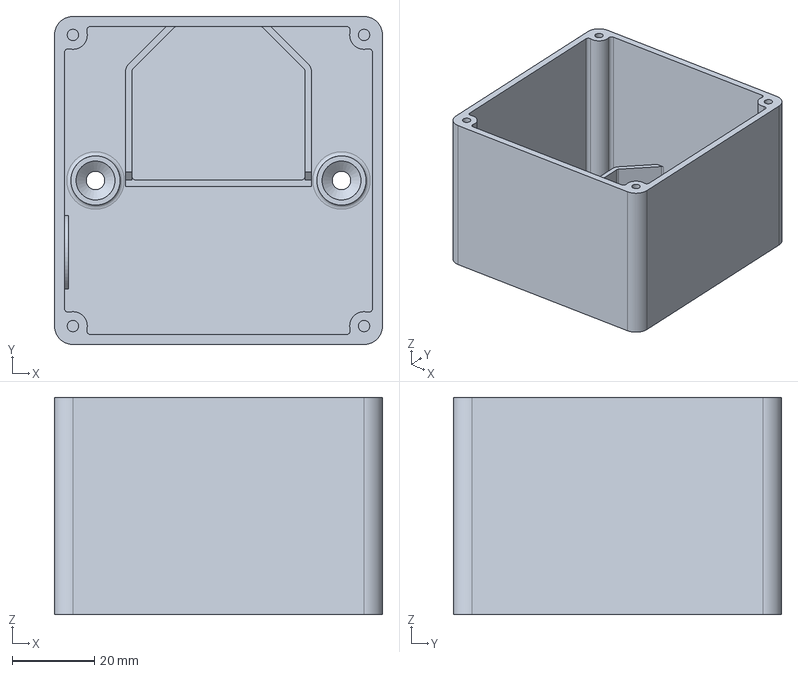
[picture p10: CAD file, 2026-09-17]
cad/Vinegar_Doser_Box_80x80x53.step
80.0 x 80.0 x 53.0 mm

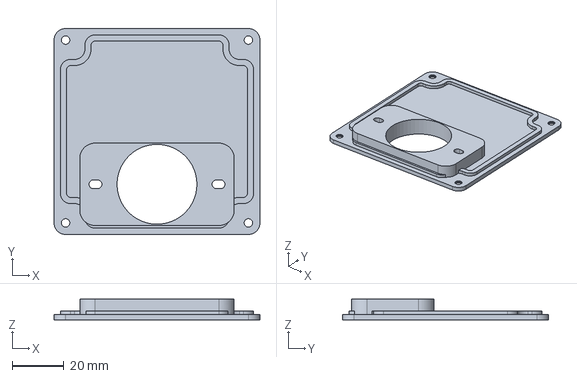
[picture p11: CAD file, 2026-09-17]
cad/Vinegar_Doser_Lid_pump_mount.step
80.0 x 80.0 x 8.00 mm

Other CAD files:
cad/Vinegar_Doser_Box_80x80x53.stl
cad/Vinegar_Doser_Lid_pump_mount.stl

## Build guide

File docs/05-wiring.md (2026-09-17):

# 05 Wiring

Everything runs on 12V DC. Six connections total.

## Terminal map

The Shelly 1 Gen4 has six terminals: **O, I, SW, 12V, L, N**.

| From | To |
|---|---|
| Barrel jack **+** | Shelly **12V** |
| Barrel jack **+** | Shelly **I** |
| Barrel jack **−** | Shelly **L** |
| Barrel jack **−** | Pump lead 1 |
| Shelly **O** | Pump lead 2 |

**SW and N stay empty.**

## Why those terminals

`12V` and `L` power the relay. On the Shelly 1 Gen4, **L is the DC negative** for both of its DC modes; the positive goes to the `12V` terminal for a 12V supply, or to `N` for 24 to 48V. The legend printed on the device shows this, and the guide in the box has a dedicated figure for a stabilised 12V supply.

**Verify this against the printed guide that came with your unit before applying power.** Reversing it is the one mistake that destroys the device.

`I` and `O` are the two sides of the dry contact, which is just an isolated switch. Feeding `I` from the positive rail means the pump only sees voltage when the relay closes. The relay itself stays powered throughout.

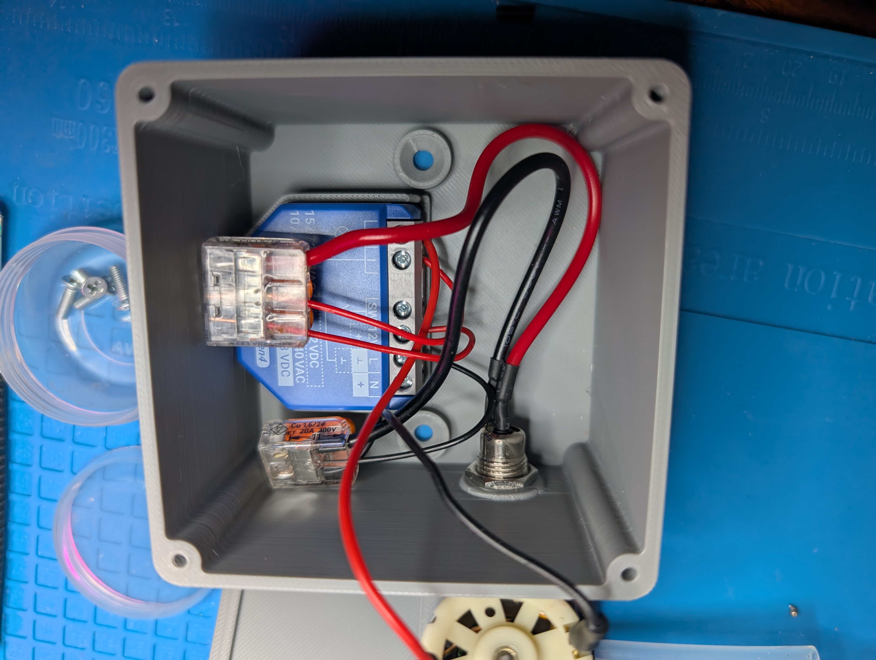
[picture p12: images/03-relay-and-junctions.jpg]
Relay seated in the box with the barrel jack and lever nut junctions

*Looking into the box: relay in its pocket, the two lever nut junction points, barrel jack threaded through the wall.*

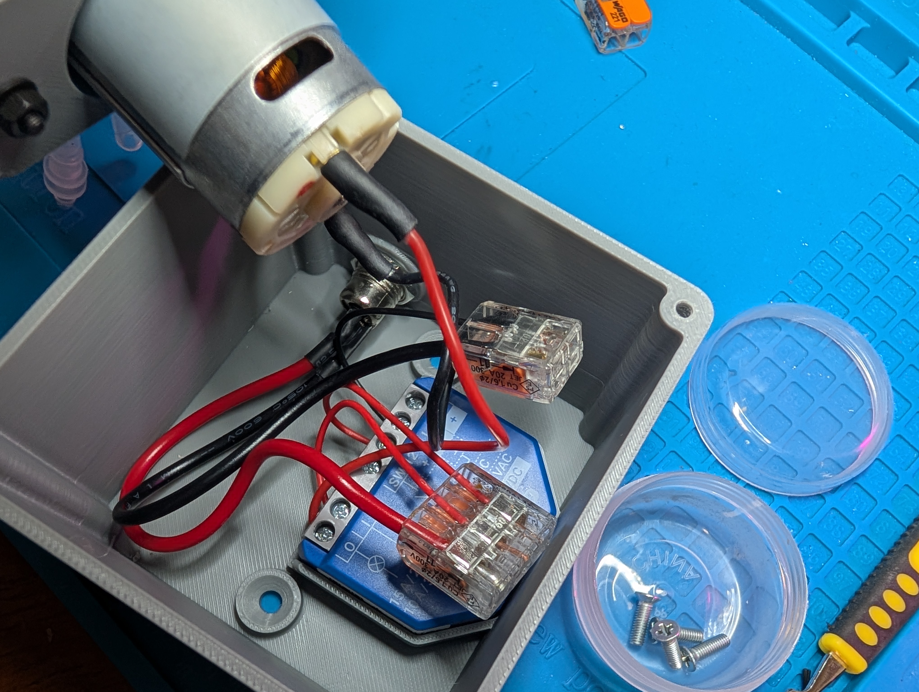
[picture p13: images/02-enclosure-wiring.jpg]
Motor leads and relay wiring joined with lever nuts

*All six connections made, lid still off. Wire it flat on a bench like this.*
## Junction points

The positive rail splits two ways and the negative rail splits two ways, so you need two junction points. WAGO lever nuts or a small terminal block. Do not try to force two wires under one Shelly screw terminal.

## Pump polarity

There is none that matters. A brushed DC motor reverses direction when you swap the leads, and a peristaltic pump works either way. If it pumps the wrong direction, swap them.

## Before you power up

**Meter the barrel jack.** Center positive is the convention, not a guarantee. Plug in the supply, probe center against sleeve, confirm you read +12 and not −12.

**Meter the supply itself, unloaded.** It should read close to 12.0 V. Older unregulated wall warts can sit at 16 to 18 V with no load, which lands between the Shelly's 12V and 24 to 48V input ranges. Any modern switching supply will be flat at 12 V.

## Assembly order

Wire everything with the lid off and the box on a bench. Once the lid is screwed down, the box is 53 mm deep and the pump is in the way.

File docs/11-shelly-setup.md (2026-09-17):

# 11 Shelly device setup

Everything done on the relay itself, in the order it should be done. These settings live in the device's own config, not in Home Assistant, and they are what protect you when Home Assistant is not there.

Written against a Shelly 1 Gen4 on firmware 2.0.0. Earlier firmware puts some of these in different places, noted where it matters.

## Decide the protocol first

The Gen4 runs WiFi, Zigbee, Matter and Bluetooth. **It will run WiFi and Zigbee at the same time**, which turns out to be the best configuration for this build.

| | WiFi | Zigbee |
|---|---|---|
| Local control | Yes | Yes |
| Device side auto off | **Yes** | **No** |
| Availability tracking in HA | **Yes** | Depends on your Z2M settings |
| Device web interface | Yes | No |
| Firmware updates | Yes | No |

**The auto off timer is the deciding factor.** See [09 Troubleshooting](09-troubleshooting.md) for the full finding, but in short: Zigbee mode silently ignores the timer, so if you only run Zigbee, nothing on the device will ever stop a stuck pump.

Running both gives you Zigbee control plus the WiFi web interface and proper availability reporting. That is what the reference build does.

## 1. First power up and WiFi

Power the relay. It broadcasts an access point named after the device.

Join that network and browse to **http://192.168.33.1**.

Go to **Settings > WiFi**, enter your network and password, and apply. The web interface shows the new IP once it connects. From then on you reach it at that address.

**Give it a DHCP reservation** in your router. The Home Assistant integration pins to the IP and the web interface is easier to find when the address holds.

## 2. Update the firmware

Do this before anything else, because **Zigbee mode cannot do OTA updates.** If you switch to Zigbee first you have to switch back to update.

Either from the device's own Settings, or from the Home Assistant update entity once the Shelly integration has it. Both trigger the same process.

Do not power cycle during the update.

## 3. Turn off Cloud

**Settings > Cloud**, toggle Enable off.

By default the device maintains a connection to a Shelly server so their app can reach it remotely. Nothing in this build uses that. Turning it off means the relay only answers to your own network.

You lose remote access from the Shelly app. Local app control and Home Assistant are unaffected.

## 4. The three settings that matter

These are the device side protections. All three survive firmware updates, but verify them afterwards anyway.

### Auto OFF: 300 seconds

**On firmware 2.0.0:** Home page, click the **output**, then the **Timers** tab under Automations. On 2.0.0 this may also appear on its own settings page.

**On 1.7.x:** same place, but the Enable checkbox does not exist. A non zero value is the enable.

Set **Auto OFF** to **300** and leave **Auto ON** at 0, which disables it.

This is the hardware watchdog. The relay counts down on its own, so a dead network, a crashed Home Assistant or a hung automation all still end with the pump off. Set it comfortably above your dose time. A 110 second dose against a 300 second ceiling leaves plenty of margin while still catching a stuck relay well before a jug empties.

### Output type: Detached

Home page, click the output, **Input/Output settings**, set output type to **Detached**.

The default is Toggle, which ties the relay to the physical SW input. **With nothing wired to SW that input floats**, and a floating input can read as a state change. Detached separates it entirely, so nothing physical can close the relay.

### Action on power on: Turn OFF

Same page, below the output type.

**Do not use "Restore last known state."** That is the right default for a light and the wrong one for a pump. If power blips mid dose, restore brings the relay back closed, and the auto off timer does not resume because the device just booted with no memory of a countdown. You would have a pump running with nothing counting down.

Turn OFF means a power interruption always ends with the pump stopped. The worst case is a missed dose, which gets caught next month.

**Current state of the switch** is worse still on a Detached setup with a floating input, since the relay would follow an unconnected pin on every boot.

## 5. Optional: add Zigbee alongside

If you want Zigbee control as well, do it now, after the firmware update and after the settings above.

**Switching wipes every setting except the WiFi configuration.** Auto off, output type and power on action all reset, so redo section 4 afterward and verify.

Two ways to switch:

- **Web interface.** A Matter to Zigbee toggle in Settings, then a Zigbee menu with Start pairing. Status reads Steering while discoverable and Joined on success.
- **Button.** Five quick presses switches profile and opens a 3 minute inclusion window. Three presses reopens it. The presses have to be genuinely fast.

## 6. Verify

After everything, confirm all three:

- Auto OFF reads 300 and is enabled
- Output type is Detached
- Action on power on is Turn OFF

Then **test the auto off.** Turn the relay on and walk away. It should shut off by itself at 300 seconds with Home Assistant doing nothing.

Do this with **water, not vinegar.** Five minutes at 135 mL/min is about 680 mL down the drain for a test. Put the inlet in a container of water and the outlet in a bucket.

If you would rather not wait five minutes, set Auto OFF to 30, test, then put it back to 300.

**Test it once.** It is the layer that matters most and the one you would least want to discover was never working.

## What you get in Home Assistant

Adding the device to the Shelly integration over WiFi gives you, alongside the switch:

- **Device temperature.** The reference build read 99.9F inside the enclosure at mid morning in September. Useful, given most small pumps are rated only to 40C.
- **Uptime**, which is how you spot unexpected reboots
- **Signal strength**
- **Firmware update entity**
- **Proper availability**, which is the thing Zigbee could not provide

If the device was discovered and ignored at some earlier point, it will be sitting under **Settings > Devices & Services > Ignored**. Un-ignore it rather than hunting for a way to add it manually.

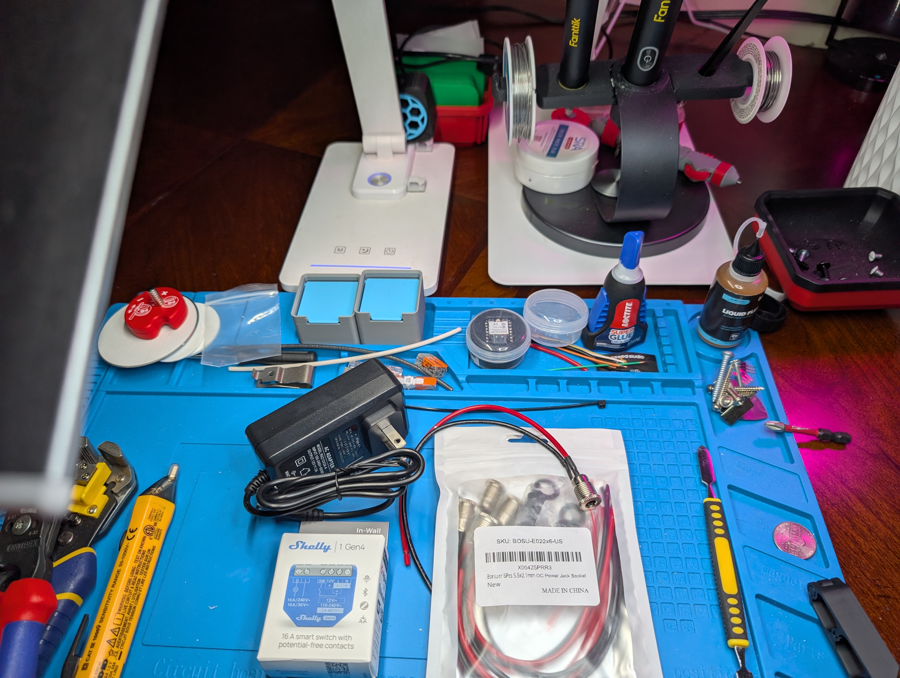
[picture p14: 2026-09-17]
images/00b-bench-setup.jpg

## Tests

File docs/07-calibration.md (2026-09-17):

# 07 Calibration

The dose is a number of seconds, not a measured volume. You have to find out how many seconds your pump takes to deliver one cup.

**Do this on a bench with water, over a sink. Not in the attic with vinegar.**

## Setup

Inlet tube into a bowl of water, outlet tube into a container. Fill the bowl generously, at least a quart, so the pump cannot suck it dry and start pulling air part way through the run.

## Prime first

Run the pump until water flows steadily out of the outlet, then stop and empty the container.

If you skip this, the priming time gets baked into your number and every real dose comes out short.

## Measure

Two methods. The second is easier to do accurately.

**Method A.** Mark one cup on your collection container first: measure a cup of water, pour it in, mark the line, empty it. Then run the pump and time how long it takes to reach the line.

**Method B.** Run for exactly 60 seconds, then pour what you collected into a measuring cup and read it. Scale from there. If you got 80 mL in a minute, a cup takes about 178 seconds.

One US cup is 237 mL.

## Set the dose time

Add about 5 seconds of margin to whatever you measured. Slightly overdosing is harmless; underdosing defeats the purpose.

The reference build measured **105 seconds per cup**, roughly 135 mL/min, and uses a **110 second** dose.

Edit the two delays in `automation.drainflo_dosing`. The sequence is a 5 second settle after turn on, then the remainder. For a 110 second total the second delay is 105 seconds. If your dose time is different, change that second delay.

## Re measure occasionally

Peristaltic tubing takes a set where the rollers compress it, and flow drops over time. Re run this test once a year.

**If a cup starts taking noticeably longer, that is your signal to replace the pump tube**, not just to increase the dose time.

## Vinegar versus water

Close enough. At 5 percent acetic acid the viscosity is near identical to water, so the number transfers.

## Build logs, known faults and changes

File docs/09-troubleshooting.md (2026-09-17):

# 09 Troubleshooting

## Known issues

### Shelly 1 Gen4 ignores on_time in Zigbee mode

**Symptom.** You publish `{"state": "ON", "on_time": 300}` to the device's Zigbee2MQTT set topic. The relay turns on and never turns off. No error appears anywhere.

**Diagnosis.** Publish `{"state": "ON"}` to the same topic. If that works, your topic is correct and the `on_time` attribute specifically is being discarded by the device.

**Cause.** The Gen4 firmware in Zigbee profile does not implement the OnOff cluster's timed off behavior. Zigbee2MQTT exposes only a plain on/off state for it, with no countdown, auto off or `on_time` entity.

**Workarounds.**
- Accept it and rely on the software cutoffs in the package. This is what the reference build does.
- Run the relay on WiFi, where the Shelly web interface has a working auto off.
- Use the ESPHome controller, which enforces its own runtime limit.

### Shelly 1 Mini Gen4 will not work in this build

It has dry contacts, but it is **AC powered only**. The spec sheet lists 110 to 240 V~ with only L and N terminals. There is no DC input. The full size Gen4 is the one that takes 12V DC.

### Switching the Shelly to Zigbee resets its settings

Everything except the WiFi configuration is wiped when the firmware profile changes. Set any device side options **after** switching, not before.

Also: **Zigbee OTA updates are not supported.** Update the firmware while it is still in WiFi or Bluetooth mode, because you cannot do it once it is on Zigbee without switching back.

---

## Symptoms

### The relay pocket is too tight for the Shelly

The pocket is 42.05 mm and the relay is 42.0 mm. Printed parts commonly come in a couple of tenths undersize.

File the inner faces of the two rails. They are 1.6 mm ribs standing in open air with access from above, and they only locate the relay, so removing 0.2 mm from each face weakens nothing.

Alternatively set an X-Y contour compensation of about −0.1 mm and reprint.

### The barrel jack will not fit the hole

The hole is 11 mm, matching the panel hole these jacks specify. If yours is tight, run a 7/16 inch bit through it. PLA drills easily; go slow and back out to clear chips.

### The pump runs but nothing comes out

- **Not primed.** Run it longer on the first go.
- **Inlet pulling air.** The pickup tube may be above the liquid, or the jug is nearly empty.
- **No vent, or a blocked vent.** The jug cannot draw air back in, so it starves or collapses. Check the vent hole.
- **Running backwards.** Swap the two pump leads.

### The jug is collapsing

The vent hole is missing, too small, or plugged. 3 mm minimum.

### Vinegar siphons out of the jug on its own

The vent tube is reaching into the liquid instead of staying in the air space above it. Shorten it.

### Doses are coming out short

Either the pump was not primed when you calibrated it, or the pump tube has taken a set and flow has dropped. Re run [07 Calibration](07-calibration.md). If the number has moved a lot, replace the tube rather than just increasing the dose time.

### The dose counter is wrong

It is open loop. Home Assistant cannot see inside the jug. If you refilled without pressing Refilled, the count is low. Set `input_number.drainflo_doses_remaining` back to 16 manually.

### "Pump did not start" notification, but the relay looks fine

The automation commands the relay on, waits 5 seconds, then checks whether it reports on. A slow or congested Zigbee network can miss that window.

Check the relay's link quality. If it is consistently poor, either improve the mesh with a router closer to the attic, or lengthen the 5 second settle delay in the automation.

### The pump fault warning will not clear

By design. It does not self clear when the relay comes back, because a missed monthly dose stays missed until someone deals with it.

Dose manually if the line still needs it, then run `script.drainflo_clear_fault` or tap Dismiss on the notification.

### Nothing dosed on the 15th

Check, in order:

1. Was `switch.drainflo` available at 05:00? Look at its history.
2. Is `automation.drainflo_dosing` enabled?
3. Did you get a fault notification? Check `input_boolean.drainflo_pump_fault`.
4. Check the automation trace in Home Assistant, which will show which branch ran and where it stopped.

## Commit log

2026-09-17 Initial commit: DrainFlo automatic condensate drain line doser
    [DrainFlo_Badge_drop_A_full_tagline.step, Vinegar_Doser_Box_80x80x53.step, Vinegar_Doser_Box_80x80x53.stl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]
2026-09-17 BOM: add product links and the WAGO lever nut connectors
2026-09-17 BOM: link remaining parts, add hookup wire, correct the build cost
2026-09-17 BOM: link power supply and leak sensor, drop placeholder links from the ESP32 table
2026-09-17 BOM: add a leak sensor options section with hub requirements
2026-09-17 Embed build photos in the README and the enclosure, wiring, plumbing and BOM docs
2026-09-17 Link the STEP and STL files directly and add a printed parts table to the README
2026-09-18 BOM: correct prices to the reference build, swap the power supply, note wire nuts as the cheap option
